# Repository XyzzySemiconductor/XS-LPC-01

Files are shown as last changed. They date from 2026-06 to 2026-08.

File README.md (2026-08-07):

   

# Tiny Tapeout Project: Liquid Pump Controller

A digital control chip to daily pump a tank empty. Approached as system design  for a whole product, of which the chip is the core but not only design work required.

- [chip datasheet](docs/LPC_Datasheet.pdf)
- [documentation for Tiny Tapeout chip](docs/info.md)
- [documentation for Tiny Tapeout tests](test/README.md)
- [documentation for MAX10 development fpga](max10/fpga.md)
- [documentation for forge production fpga](forge/forge.md)
- [documentation for the Dev board PCB](pcb/pcb.md)

Branches:
- main - TT design forefront, and Max 10M25 fpga accel of full system sims with hdmi display.
- lpc_emu - Max 10M04 fpga HW emulating the full TT chip (hdmi monitoring)
- lpc_test - Max 10M04 system emulator, chip testing or emulator testing.
- lpc_mon - Max 10M04 chip monitor, passive observation (hdmi)
  
## What is Tiny Tapeout?

Tiny Tapeout is an educational project that aims to make it easier and cheaper than ever to get your digital and analog designs manufactured on a real chip.

To learn more and get started, visit https://tinytapeout.com.

## Set up your Verilog project

1. Add your Verilog files to the `src` folder.
2. Edit the [info.yaml](info.yaml) and update information about your project, paying special attention to the `source_files` and `top_module` properties. If you are upgrading an existing Tiny Tapeout project, check out our [online info.yaml migration tool](https://tinytapeout.github.io/tt-yaml-upgrade-tool/).
3. Edit [docs/info.md](docs/info.md) and add a description of your project.
4. Adapt the testbench to your design. See [test/README.md](test/README.md) for more information.

The GitHub action will automatically build the ASIC files using [LibreLane](https://www.zerotoasiccourse.com/terminology/librelane/).

## Enable GitHub actions to build the results page

- [Enabling GitHub Pages](https://tinytapeout.com/faq/#my-github-action-is-failing-on-the-pages-part)

## Resources

- [FAQ](https://tinytapeout.com/faq/)
- [Digital design lessons](https://tinytapeout.com/digital_design/)
- [Learn how semiconductors work](https://tinytapeout.com/siliwiz/)
- [Join the community](https://tinytapeout.com/discord)
- [Build your design locally](https://www.tinytapeout.com/guides/local-hardening/)

## What next?

- [Submit your design to the next shuttle](https://app.tinytapeout.com/).
- Edit [this README](README.md) and explain your design, how it works, and how to test it.
- Share your project on your social network of choice:
  - LinkedIn [#tinytapeout](https://www.linkedin.com/search/results/content/?keywords=%23tinytapeout) [@TinyTapeout](https://www.linkedin.com/company/100708654/)
  - Mastodon [#tinytapeout](https://chaos.social/tags/tinytapeout) [@matthewvenn](https://chaos.social/@matthewvenn)
  - X (formerly Twitter) [#tinytapeout](https://twitter.com/hashtag/tinytapeout) [@tinytapeout](https://twitter.com/tinytapeout)
  - Bluesky [@tinytapeout.com](https://bsky.app/profile/tinytapeout.com)

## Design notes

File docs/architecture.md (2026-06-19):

### architecture

for now here's a quick block diagram

    +------------------+      +------------------+      +------------------+
    | Pump Current In  | ---> |  LPC Controller  | ---> | PWM Drive Output |
    +------------------+      |  - Thresholds    |      +------------------+
                              |  - Shutdown FSM  |
    +------------------+      |  - Debounce      |      +------------------+
    | AC Zero Detect   | ---> |  - Timing Logic  | ---> | Status / Debug   |
    +------------------+      +------------------+      +------------------+

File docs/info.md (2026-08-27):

<!---

This file is used to generate your project datasheet. Please fill in the information below and delete any unused
sections.

You can also include images in this folder and reference them in the markdown. Each image must be less than
512 kb in size, and the combined size of all images must be less than 1 MB.
-->

## How it works

A pump-out chip runs a pump until the tank is empty. A liquid pump controller, or LPC. The chips function is upon power up, and every 24hrs, turn on the pump, and using a current transformer (CT) measures the 60 Hz RMS current and observe a current drop indicating the tank has been emptied, or until a timeout has occurred and then turn off the pump. Leds indicate status, and button allows starting a pump out operation at any time.

A chip starts with a [Datasheet](LPC_Datasheet.pdf) where features are fleshed out, and boiled down to a few key diagrams: the chip block diagram, the system diagram, and a development platform to be used to bring up the chip as part of a product development. These are all before doing any design.

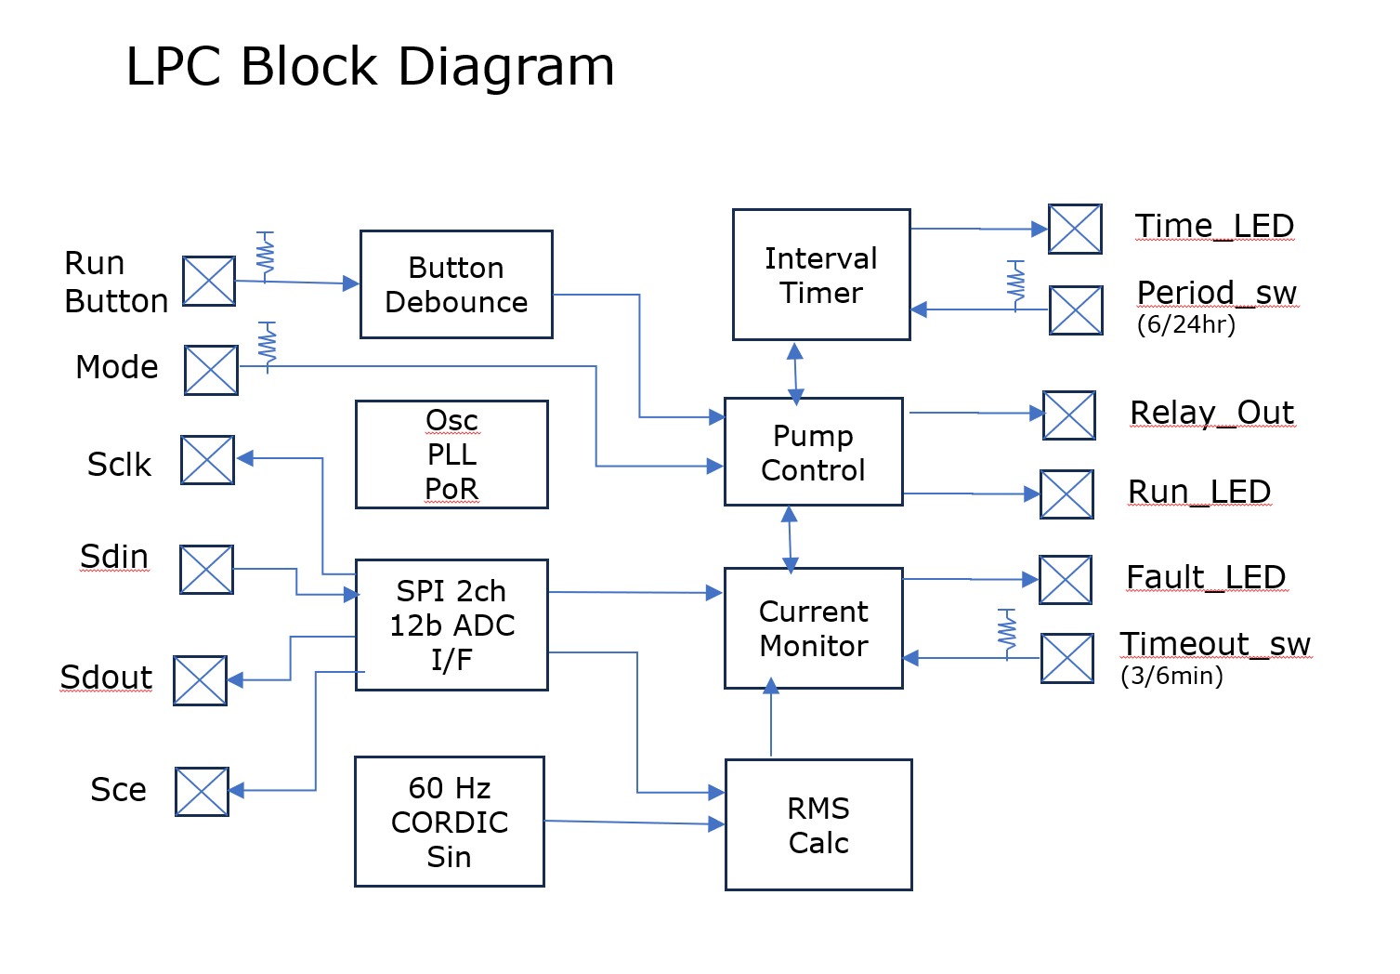
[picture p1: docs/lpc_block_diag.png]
Block Diagram


The chip  block diagram showing the key modules and critically the I/O and how it relates to the functions. A crisp clear picture of the chip's architecture.

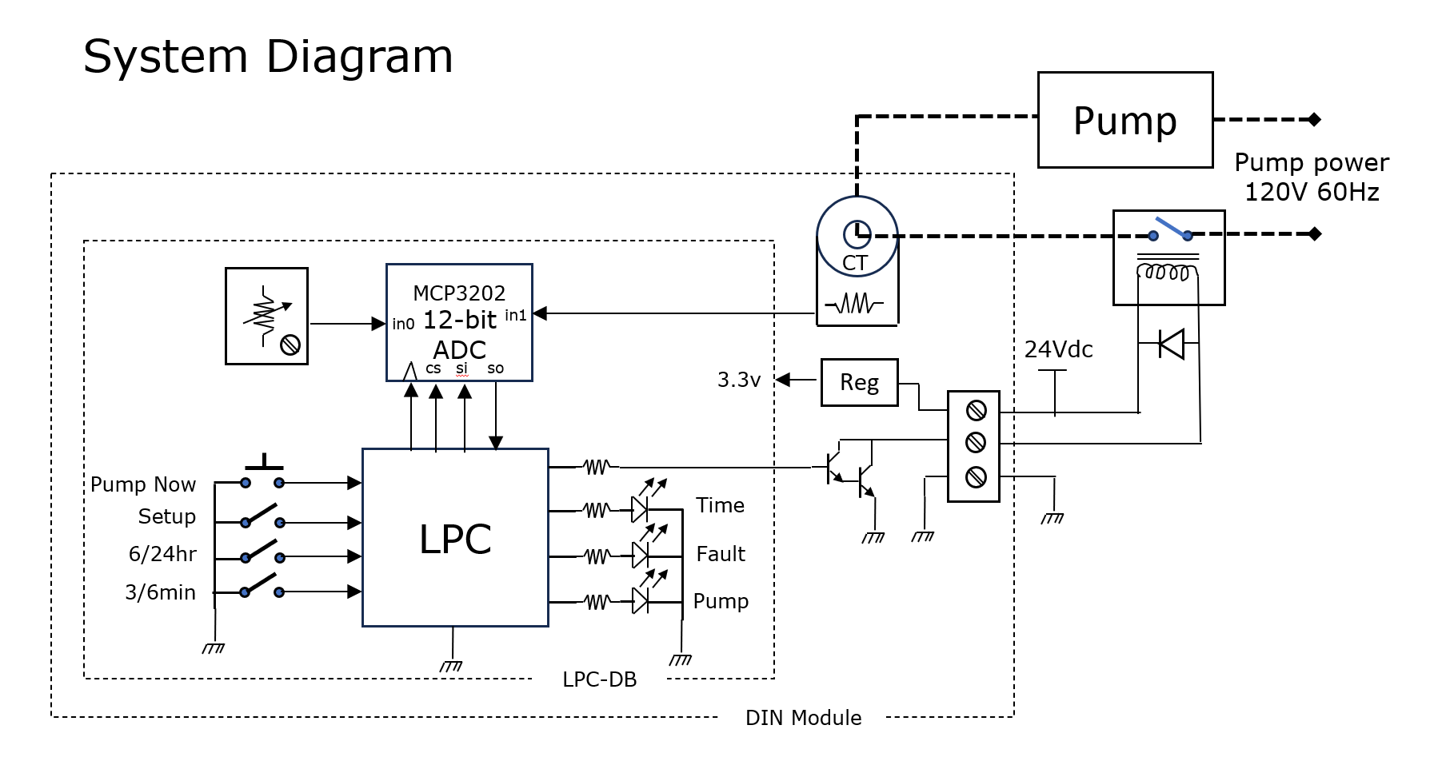
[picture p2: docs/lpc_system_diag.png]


The system diagram provides the context of the chip. How do the I/O connect to the rest of the system, what part of the system function is inside the chip and what part is outside. Another crisp clear picture of the chip from the outside.

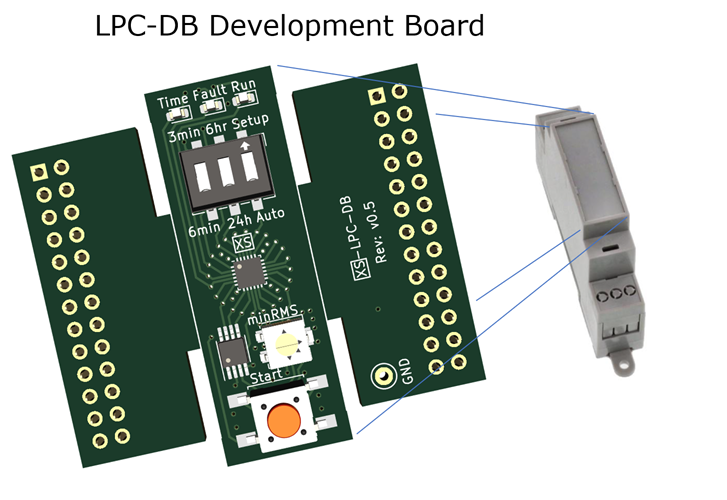
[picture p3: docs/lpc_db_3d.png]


In order to bring up a new chip requires a way to bring it to life. A development board is one way. Such a board provides a means to connect the chip into the system, and enable bring up and validation of the device an enable rapid product development by enabling full observability and emulation. 

For the LPC chip development board heart a 24 pin 3mm forge fpga with cut-away emulator wings. From the top we have the time, fault, run leds, the control dip switch, the LPC chip, a 2ch adc, potentiometer, and button.

## How to test

How did I test the design, and how should the chip be tested when it returns.

Design testing:

RTL testing at 16x speedup (changed internal dividers), with the testbench including ADC model, and a plant model. Used verilator to greatly speed up itterations, but still ran the TT icarus precision flow.

GL testing is much shorter, but one thing it does validate is to make sure the 16x speedup is not included in the gates (always fear parameters).

FPGA Max10 testing. Even with verilator full system simulation was not possible given the 24hour duty cycle, 15x true real time was used with the ADC and plant models being synthesized into the fpga along with the LPC_core.sv

Chip Testing

A FPGA Max 10 chip tester was designed by putting the adc model and plant model into an fpga. To test this a 2nd Max 10 was setup as a chip emulator, and to observe the interaction between the 2 a 3rd Max 10 was setup as a monitor with 32MByte of storage PSRAM and HDMI vga, fully observed teh chips's I/O. All of these boards inteconnected via the LPC dev board emulation header. Teh TT chip will plug into this emulation header with the Tester and Monitor FPGAs.

A development board was fully designed and implemented with the chip I/O all wired to emulation headers. The TT develoement board pmods will be jump wired to the emulation header pins. The Max10 monitor fpga board will be able to observe the interaction between the TT chip and the LPC dev board. The LPC dev board connects to a power board contain the CT (current transformer) and pump relay. The bring up of the dev board used the chip Max 10 emulator and the Max 10 monitor.

Renesas forge 1k-lut OTP fpga emulation of the TT chip. I find these chips are about the equivalent of a 1x2 TT design with similar (less) I/O. They are self contained with build in Osc, PLL, and power on reset, and configure from OTP in 10ms. The LPC design was ported and implemented in a Forge fpga. The FPGA itself was tested against the Max10 tester, and then connected to the dev board by the emulation header, and penultimately soldered onto the dev board, and run in-system.

## External hardware

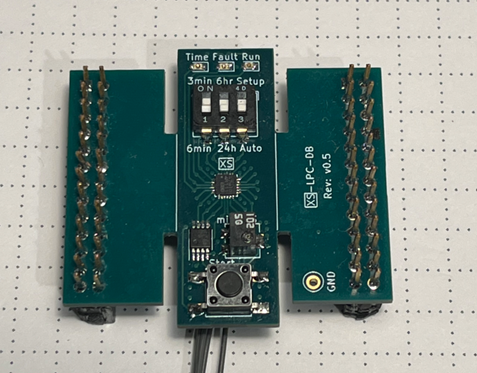
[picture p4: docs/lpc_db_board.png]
Development Board


The LPC dev board with the 3mm x 3mm forge fpga mounted. This board has been tested in system. The TT dev baord can be jumpered to the header (and the forge held in reset) to allow full system testing.

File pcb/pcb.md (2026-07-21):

### LPC Development board.

The LPC-DB PCB is a development board used to bring up and validate the LPC pump-controller ASIC by providing a controlled, 
low-voltage environment for CT sensing, signal conditioning, adc and digital interfacing during early hardware testing. 
It contains the CT burden input stage, protection components, calibration path, regulated supplies, and 
emulation header instrumenting the LPC chip IO. With the emulators wings clipped, 
the fits in the face of a Din rail module for field testing.

It does not switch mains and relies on external hardware for pump actuation.

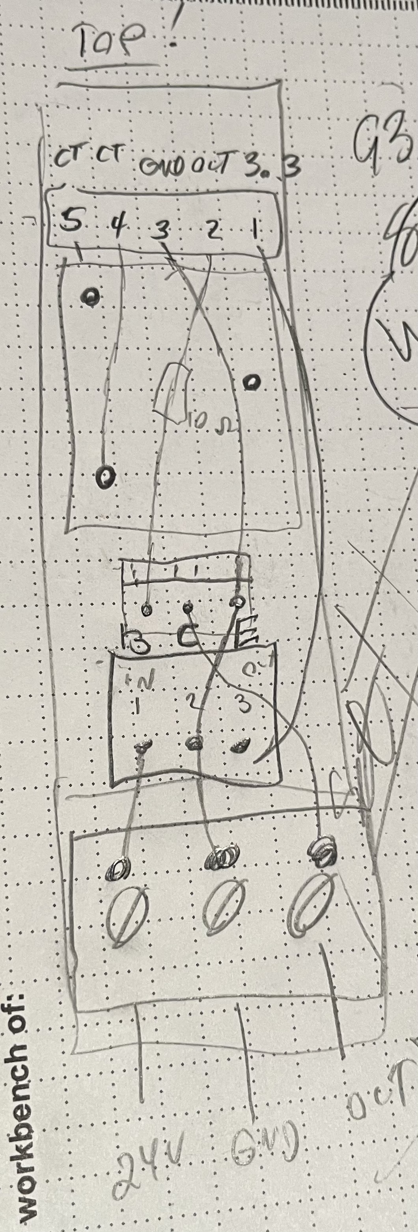
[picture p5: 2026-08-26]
docs/din_lower_schematic.jpeg

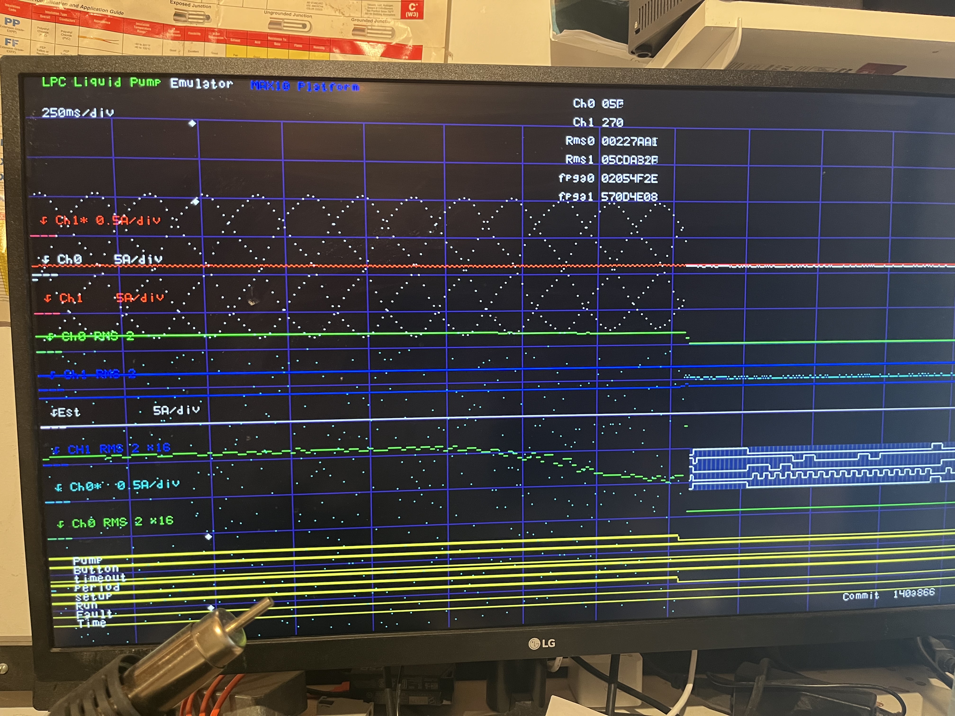
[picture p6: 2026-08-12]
docs/140a866_field_run_pump_empty_02.jpeg

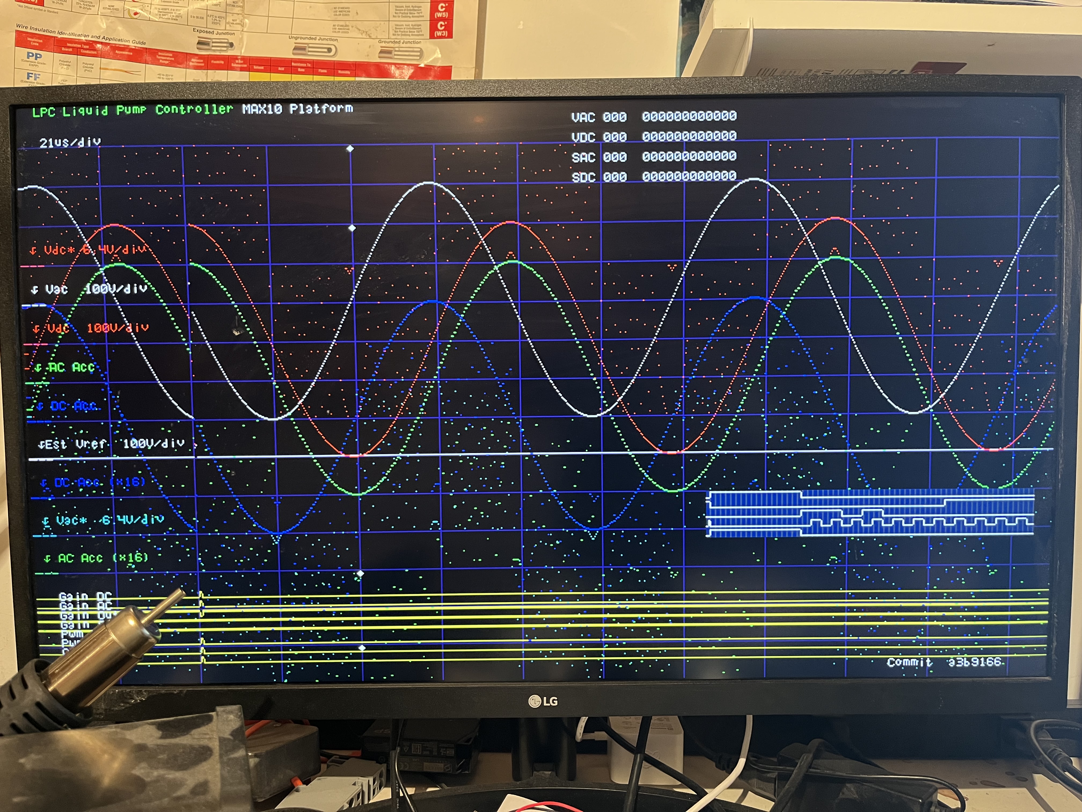
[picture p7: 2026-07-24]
docs/a3b9166.jpeg

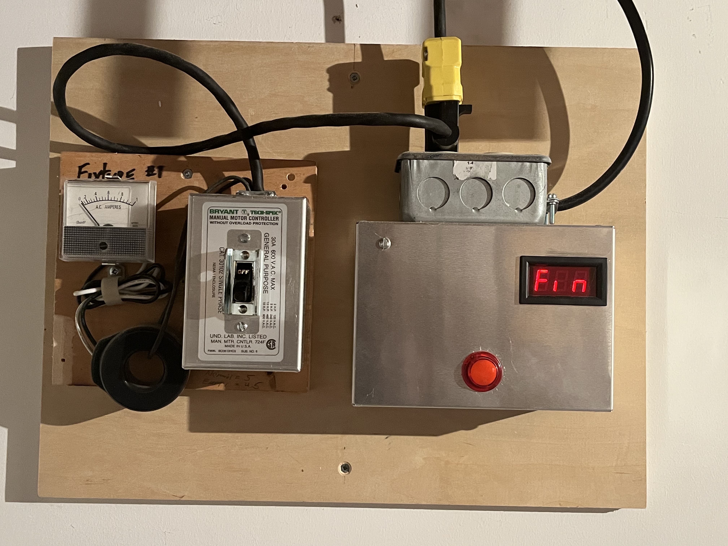
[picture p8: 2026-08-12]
docs/140a866_field_run_pump_empty_05.jpeg

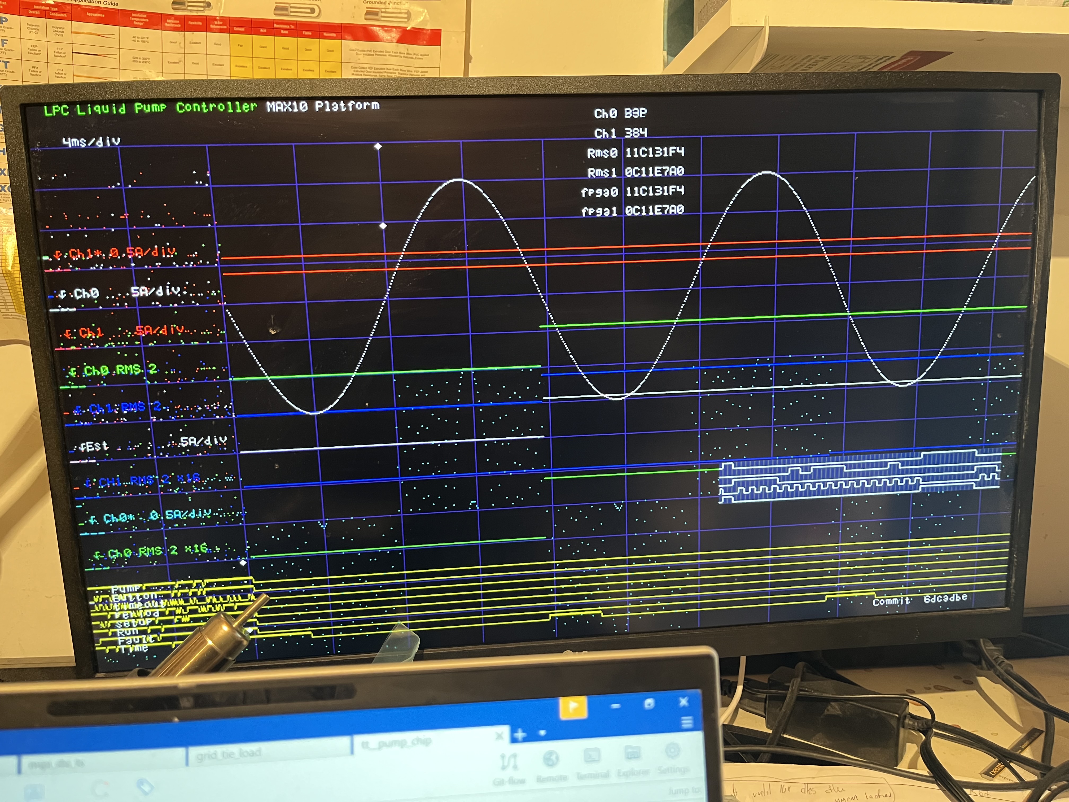
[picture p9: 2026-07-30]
docs/6dcadbe.jpeg

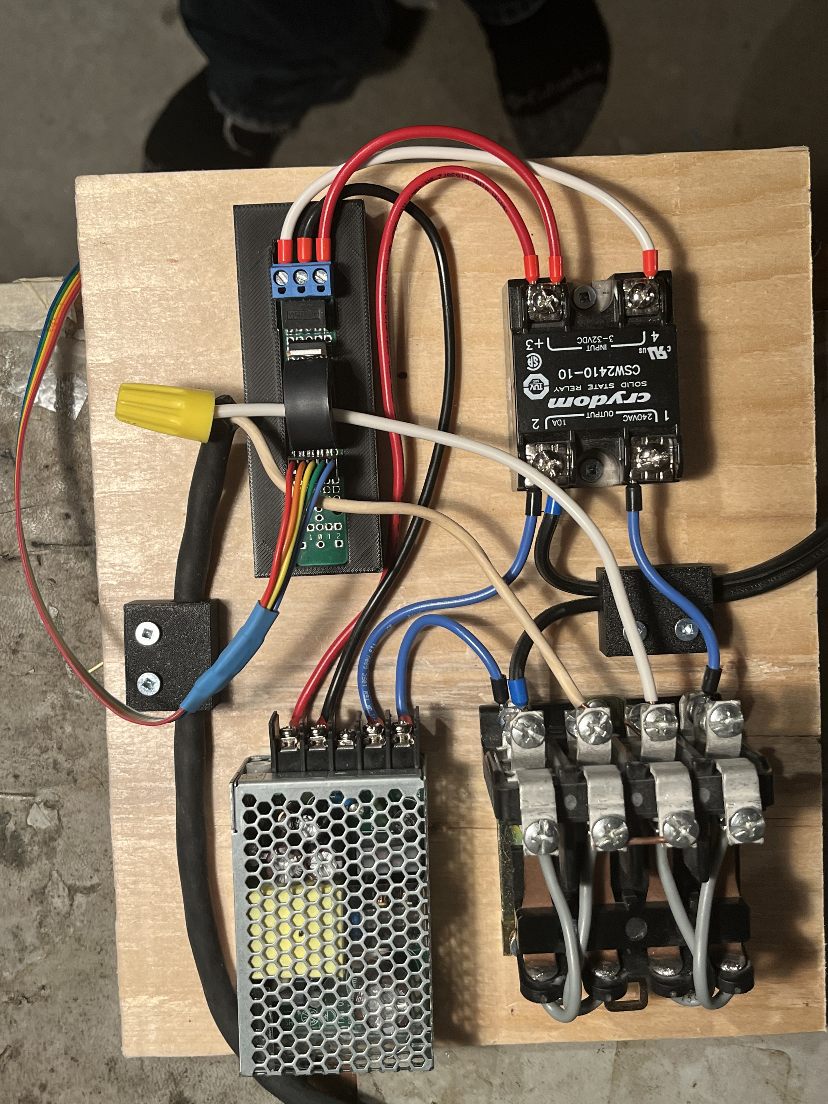
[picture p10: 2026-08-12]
docs/140a866_field_run_pump_empty_04.jpeg

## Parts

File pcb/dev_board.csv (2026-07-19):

Reference | Value | Footprint | Datasheet | DPN | Qty
C1, C2, C4, C9, C10 | 1u | Capacitor_SMD:C_0603_1608Metric | ~ | 399-C0603C105K3RAC7867CT-ND | 5
C3, C5, C6 | 22n | Capacitor_SMD:C_0603_1608Metric | ~ | 445-5663-1-ND | 3
C8 | 4.7u | Capacitor_SMD:C_1206_3216Metric | ~ | 399-C1206C475K5PAC7800CT-ND | 1
C11 | 0.1u | Capacitor_SMD:C_0603_1608Metric | ~ | 399-C0603C104K3RAC7867CT-ND | 1
C12 | 10u | Capacitor_SMD:C_1206_3216Metric | ~ | 399-C1206C106K4PAC7800CT-ND | 1
D1 | RUN | LED_SMD:LED_0603_1608Metric | https://www.digikey.ca/en/products/detail/kingbright/APTD1608LSYCK/7043071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 | 754-2039-1-ND | 1
D2 | FLT | LED_SMD:LED_0603_1608Metric | https://www.digikey.ca/en/products/detail/kingbright/APTD1608LSYCK/7043071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 | 754-2039-1-ND | 1
D3 | TME | LED_SMD:LED_0603_1608Metric | https://www.digikey.ca/en/products/detail/kingbright/APTD1608LSYCK/7043071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 | 754-2039-1-ND | 1
D6 | DT1042-04SO-7 | Package_TO_SOT_SMD:SOT-23-6 | https://www.digikey.ca/en/products/detail/diodes-incorporated/DT1042-04SO-7/4457877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 | DT1042-04SO-7DICT-ND | 1
J1, J2 | Conn_02x13_Odd_Even | Connector_PinSocket_2.54mm:PinSocket_2x13_P2.54mm_Vertical | https://www.digikey.ca/en/products/detail/samtec-inc/ESW-113-12-T-D/7207386 | ESW-113-12-T-D-ND | 2
J4 | Conn_01x05 | Connector_JST:CONN_B5B-ZR-SM4-TF_JST | https://www.digikey.ca/en/products/detail/jst-sales-america-inc/B5B-ZR-SM4-TF/926591 | 455-1684-1-ND | 1
R1 | 0R | Resistor_SMD:R_0603_1608Metric |  | P0.0GCT-ND | 1
R2-R4, R6, R7 | 1K | Resistor_SMD:R_0603_1608Metric |  | 541-1.00KHCT-ND | 5
R5 | DNI | Resistor_SMD:R_0603_1608Metric |  | ~ | 1
R8, R11-R14, R16 | 47 | Resistor_SMD:R_0603_1608Metric |  | 541-47.0HCT-ND | 6
R9 | 3k3 | Resistor_SMD:R_0603_1608Metric |  | 311-3.30KHRCT-ND | 1
R10 | 1K | Potentiometer_SMD:Potentiometer_Bourns_3224J_Horizontal | https://www.digikey.ca/en/products/detail/nidec-components/SM-42TW102/1632327 | SM-42TW102CT-ND | 1
SW1 | SW_DIP_x03 | Button_Switch_SMD:SW_DIP_SPSTx03_Slide_6.7x9.18mm_W6.73mm_P2.54mm_LowProfile_JPin |  | 563-CFS-0300TACT-ND | 1
SW2 | Start | myspace pcb:SW_SPST_HP03 | https://www.digikey.ca/en/products/detail/nkk-switches/HP0315AFKP2-R/1242035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 | 360-2595-1-ND | 1
U1 | XS-LPC-01 | myspace pcb:QFN-24-3x3mm | https://github.com/ericpearson1313/tt_pump_out_chip | ~ | 1
U2 | MCP3202 | Package_SO:MSOP-8_3x3mm_P0.65mm | https://ww1.microchip.com/downloads/aemDocuments/documents/APID/ProductDocuments/DataSheets/21034F.pdf | MCP3202-CI/MS-ND | 1
U3 | NCP114ASN280T1G | Package_TO_SOT_SMD:SOT-23-5 | https://www.digikey.ca/en/products/detail/onsemi/NCP114ASN280T1G/6560603 | NCP114ASN280T1GOSCT-ND | 1
U6 | TLV74311 | Package_TO_SOT_SMD:SOT-23-5 | https://www.digikey.ca/en/products/detail/texas-instruments/TLV74311PDBVR/7593919 | 296-50002-1-ND | 1

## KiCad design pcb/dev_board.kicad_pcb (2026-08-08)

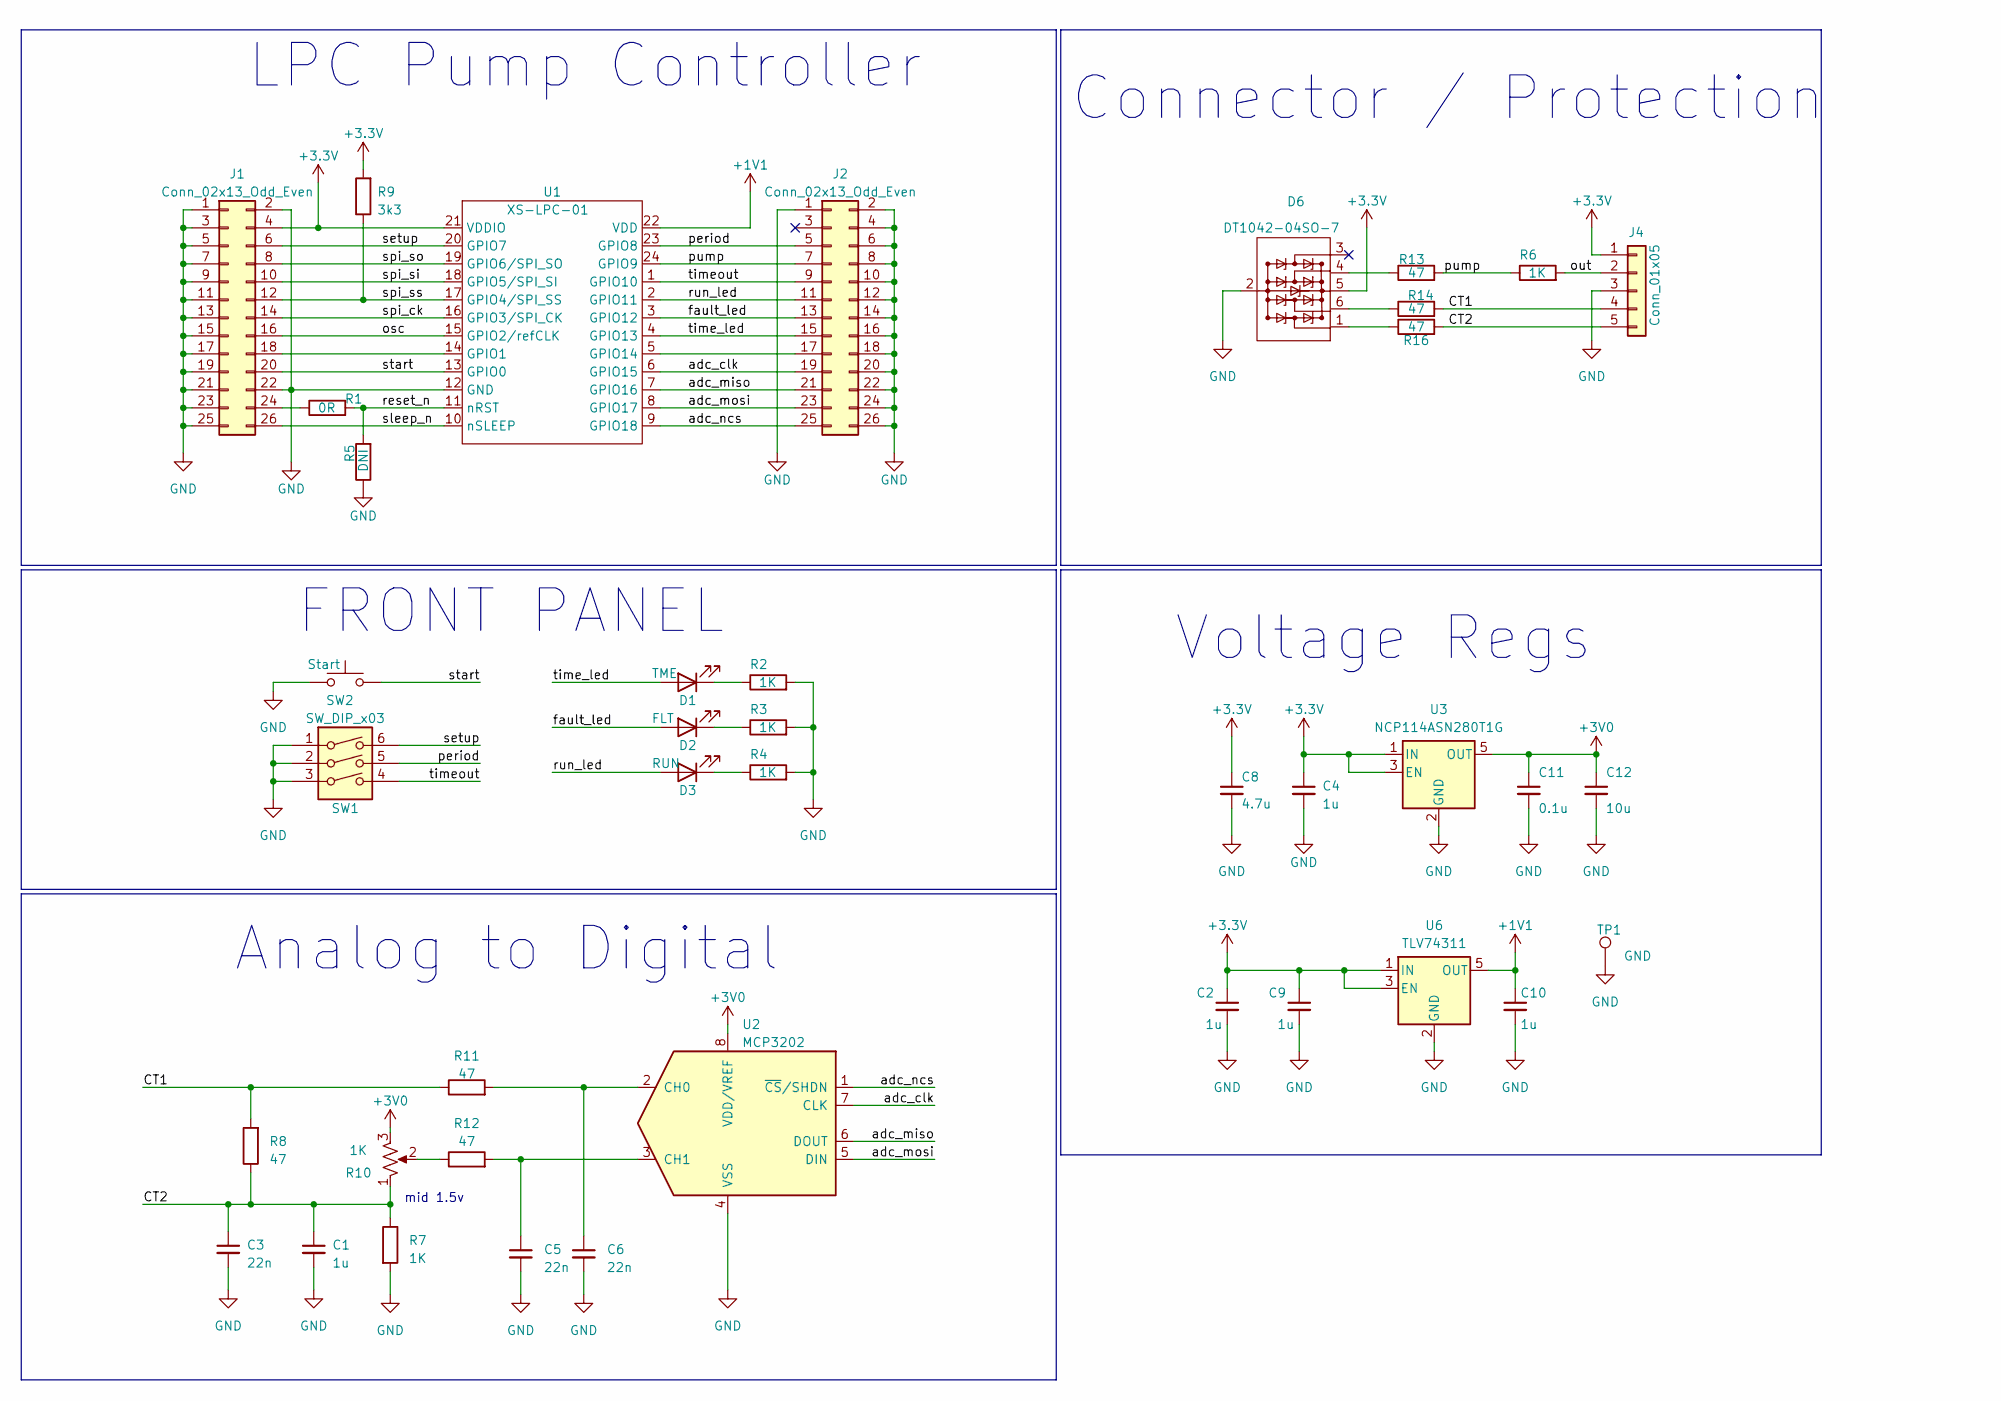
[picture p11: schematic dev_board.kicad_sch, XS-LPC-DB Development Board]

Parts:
C1, C2, C4, C9, C10: 1u; C_0603_1608Metric
C3, C5, C6: 22n; C_0603_1608Metric
C8: 4.7u; C_1206_3216Metric
C11: 0.1u; C_0603_1608Metric
C12: 10u; C_1206_3216Metric
D1: TME; LED_0603_1608Metric
D2: FLT; LED_0603_1608Metric
D3: RUN; LED_0603_1608Metric
D6: DT1042-04SO-7; SOT-23-6
J1, J2: Conn_02x13_Odd_Even; PinSocket_2x13_P2.54mm_Vertical
J4: Conn_01x05; CONN_B5B-ZR-SM4-TF_JST
R1: 0R; R_0603_1608Metric; JLC C491211
R2, R3, R4, R6, R7: 1K; R_0603_1608Metric; JLC C319967
R5: DNI; R_0603_1608Metric; JLC C491211
R8, R11, R12, R13, R14, R16: 47; R_0603_1608Metric; JLC C319967
R9: 3k3; R_0603_1608Metric; JLC C319967
R10: 1K; Potentiometer_Bourns_3224J_Horizontal
SW1: SW_DIP_x03; SW_DIP_SPSTx03_Slide_6.7x9.18mm_W6.73mm_P2.54mm_LowProfile_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
SW2: Start; SW_SPST_HP03
TP1: GND; TestPoint_Keystone_5000-5004_Miniature
U1: XS-LPC-01; QFN-24-3x3mm
U2: MCP3202; MSOP-8_3x3mm_P0.65mm
U3: NCP114ASN280T1G; SOT-23-5
U6: TLV74311; SOT-23-5

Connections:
+1V1: C10.1, U1.22 (VDD), U6.5 (OUT)
+3.3V: C2.1, C4.1, C8.1, C9.1, D6.5 (vdd), J1.4, J4.1, R9.2, U1.21 (VDDIO), U3.1 (IN), U3.3 (EN), U6.1 (IN), U6.3 (EN)
+3V0: C11.1, C12.1, R10.3, U2.8 (VDD/VREF), U3.5 (OUT)
/CT1: J4.4, R8.2, R11.1, R14.2
/CT2: C1.1, C3.1, J4.5, R7.1, R8.1, R10.1, R16.2
/adc_clk: J2.19, U1.6 (GPIO15), U2.7 (CLK)
/adc_miso: J2.21, U1.7 (GPIO16), U2.6 (DOUT)
/adc_mosi: J2.23, U1.8 (GPIO17), U2.5 (DIN)
/adc_ncs: J2.25, U1.9 (GPIO18), U2.1 (~CS/SHDN)
/fault_led: D2.2 (A), J2.13, U1.3 (GPIO12)
/osc: J1.16, U1.15 (GPIO2/refCLK)
/out: J4.2, R6.2
/period: J2.5, SW1.5, U1.23 (GPIO8)
/pump: J2.7, R6.1, R13.2, U1.24 (GPIO9)
/reset_n: R1.2, R5.2, U1.11 (nRST)
/run_led: D3.2 (A), J2.11, U1.2 (GPIO11)
/setup: J1.6, SW1.6, U1.20 (GPIO7)
/sleep_n: J1.26, U1.10 (nSLEEP)
/spi_ck: J1.14, U1.16 (GPIO3/SPI_CK)
/spi_si: J1.10, U1.18 (GPIO5/SPI_SI)
/spi_so: J1.8, U1.19 (GPIO6/SPI_SO)
/spi_ss: J1.12, R9.1, U1.17 (GPIO4/SPI_SS)
/start: J1.20, SW2.2, U1.13 (GPIO0)
/time_led: D1.2 (A), J2.15, U1.4 (GPIO13)
/timeout: J2.9, SW1.4, U1.1 (GPIO10)
GND: C1.2, C2.2, C3.2, C4.2, C5.2, C6.2, C8.2, C9.2, C10.2, C11.2, C12.2, D6.2 (vss), J1.1, J1.2, J1.3, J1.5, J1.7, J1.9, J1.11, J1.13, J1.15, J1.17, J1.19, J1.21, J1.22, J1.23, J1.25, J2.1, J2.2, J2.4, J2.6, J2.8, J2.10, J2.12, J2.14, J2.16, J2.18, J2.20, J2.22, J2.24, J2.26, J4.3, R2.2, R3.2, R4.2, R5.1, R7.2, SW1.1, SW1.2, SW1.3, SW2.1, TP1.1, U1.12 (GND), U2.4 (VSS), U3.2 (GND), U6.2 (GND)
unnamed: D1.1 (K), R2.1
unnamed: D2.1 (K), R3.1
unnamed: D3.1 (K), R4.1
unnamed: D6.4 (K1), R13.1
unnamed: D6.6 (K2), R14.1
unnamed: D6.1 (X1), R16.1
unnamed: J1.18, U1.14 (GPIO1)
unnamed: J1.24, R1.1
unnamed: J2.17, U1.5 (GPIO14)
unnamed: R10.2, R12.1
unnamed: C6.1, R11.2, U2.2 (CH0)
unnamed: C5.1, R12.2, U2.3 (CH1)

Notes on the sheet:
LPC Pump Controller
Voltage Regs
FRONT PANEL
Connector / Protection
Analog to Digital
mid 1.5v

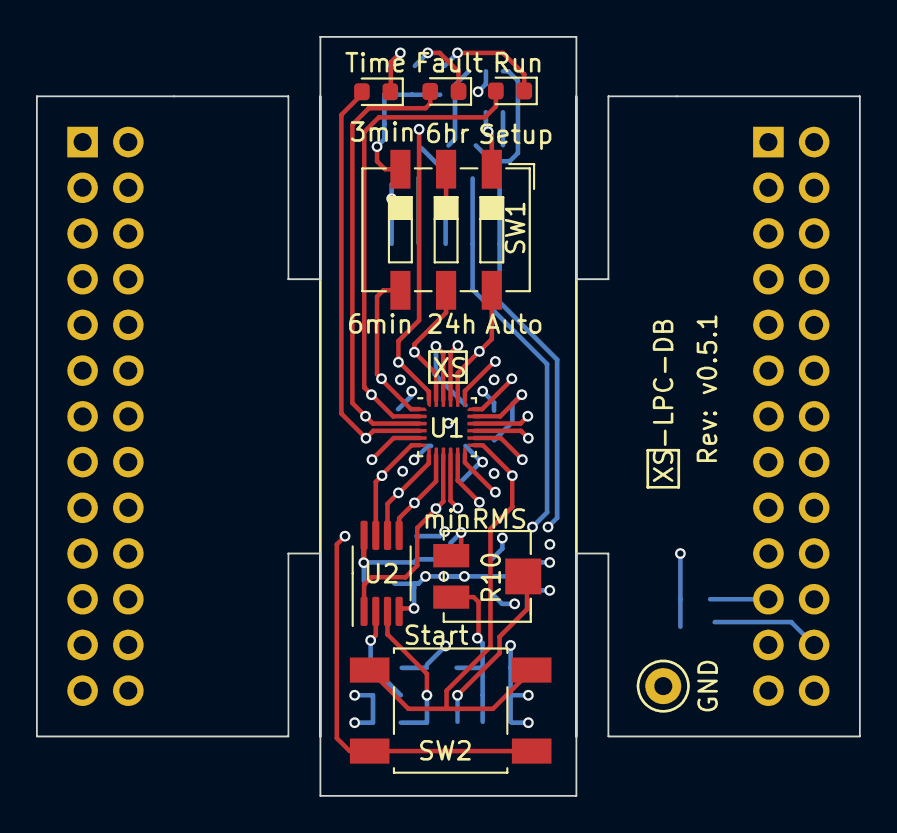
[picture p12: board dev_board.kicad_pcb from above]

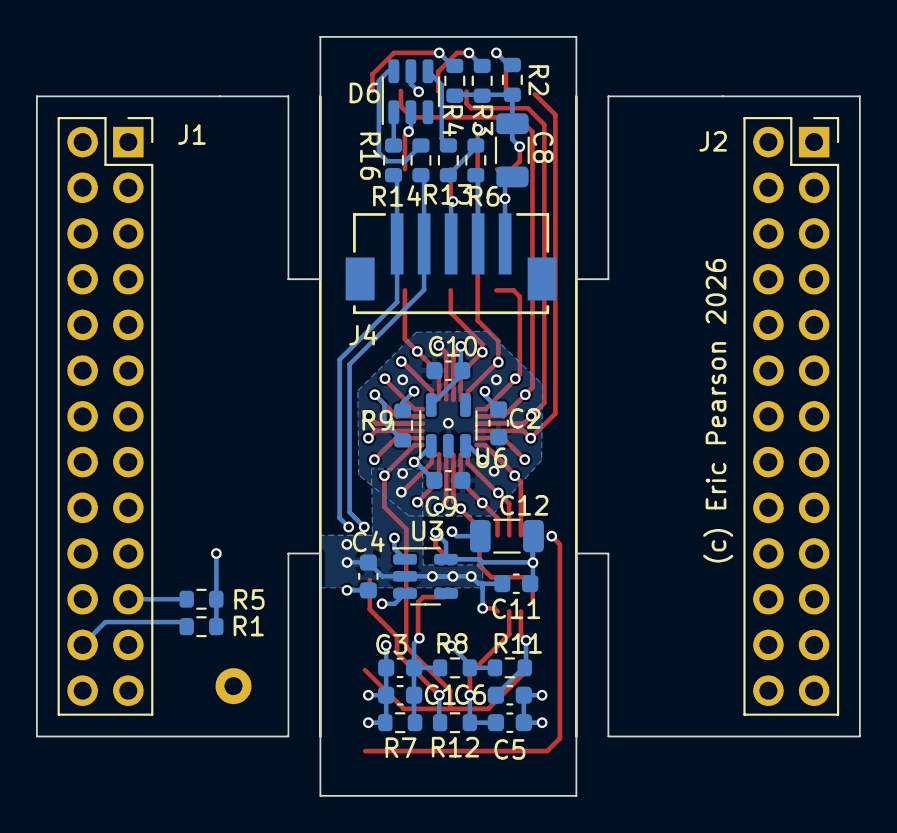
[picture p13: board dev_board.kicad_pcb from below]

Board: 6 copper layers, 45.7 x 42.2 mm, 40 parts (31 on the bottom side), 38 nets.

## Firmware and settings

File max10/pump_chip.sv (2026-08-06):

// vim: ts=4:
`timescale 1ns / 1ps
module pump_chip

#(
	// Parameter Declarations
	parameter UNIQ_ID = 32'h0000_0000
)

(
	/////////////
	// LPC CHIP IO
	/////////////

	// Input Buttons
	//input  logic button, // pin 140

	// Output LED/SPK
	//output logic time_led, // pin 101
	//output logic fault_led, // pin 99
	//output logic run_led, // pin 100
	//output logic pump_out, // pin 124

	// External Current Control Input
	//input	 logic setup_sw,  // pin 62 
	//input  logic period_sw,  // pin 135
	//input  logic timeout_sw, // pin 66 

	// ADC I/O (spi)
	//output logic adc_ncs,  // pin 132
	//output logic adc_clk,  // pin 105
	//input  logic adc_miso, // pin 106
	//output logic adc_mosi, // pin 65 

	////////////
	// DEBUG IO
	////////////
	
	// Bank 1A: emualtor LEDs
	output [8:1] anain,
	
	// Bank 7, keypad input
	inout [6:0] digio,

	
	// SPI8 Bus, to PSRAM
	inout  wire [7:0]  spi8_data_pad,   //   pad_io.export
	inout  wire spi_clk0,
	inout  wire spi_ncs,
	inout  wire spi_ds,
	inout  wire spi_nrst,
	
	// HDMI Output (Tru LVDS)
	output logic		hdmi2_d0,
	output logic		hdmi2_d1,
	output logic		hdmi2_d2,
	output logic      hdmi2_ck,
	
	// Input clock, reset
	output logic clk_out, // Differential output
	input logic clk_in,	 // Reference 48Mhz or other
	input logic reset_n
);

	// all I/O is internally emulated in the code as we are a full simulation
	logic adc_ncs;   	// pin 132
	logic adc_clk;   	// pin 105
	logic adc_miso;  	// pin 106
	logic adc_mosi;  	// pin 65 
	logic setup_sw;  	// pin 62 
	logic period_sw; 	// pin 135
	logic timeout_sw;	// pin 66 
	logic button; 		// pin 140
	logic time_led; 	// pin 101
	logic fault_led; 	// pin 99
	logic run_led; 	// pin 100
	logic pump_out; 	// pin 124



	logic [4:0] key; // keypad, bit 4 indicates pressed

	// PLL (only 1 PLL in E144 package!)

	logic clk;	// global 48Mhz clock
	logic clk4; // global 192MhZ spi8 clk
	logic hdmi_clk; 	// Pixel clk, apparentlyi can support 720p
	logic hdmi_clk5;  // 5x pixel clk clock for data xmit, 10b*3=30/3lanes=10ddr=5 

	trial_pll _spll(
		.inclk0 (clk_in),		// External clock input
		.c0     (clk_out), 	// Flash Clock 6Mhz, also External clock output differential
		.c1	  (clk),			// Global Clock ADC rate 48 Mhz
		.c2	  (clk4),		// Global Clock SPI8 rate 192 Mhz
		.c3	  (hdmi_clk),	// HDMI pixel clk
		.c4	  (hdmi_clk5)  // HDMI ddr clock 5x
		);
		
	// delayed from fpga config and external reset d-assert

	logic [3:0] reset_shift = 0; // initial value upon config
	always @(posedge clk) begin
			if( !reset_n ) begin
				reset_shift <= 4'h0;
			end else begin
				if( reset_shift != 4'HF ) begin
					reset_shift[3:0] <= reset_shift[3:0] + 4'h1;
				end else begin
					reset_shift[3:0] <= reset_shift[3:0];
				end
			end
	end

	logic reset;
	assign reset = (reset_shift[3:0] != 4'hF) ? 1'b1 : 1'b0; // reset de-asserted after all bit shifted in 


	// AIN LED Display with counter
	assign anain[4:1] = ~{ time_led, fault_led, run_led, pump_out }; // active low leds

	logic [24:0] count;
	always @(posedge clk) begin
		count <= count + 1;
	end
	assign anain[8:5] = 3'b111; //count[24:21];


	/////////////////////////////////
	/////////////////////////////////
	////
	////  Pump Chip (DUT) 
	////
	/////////////////////////////////
	/////////////////////////////////

  // Fpga probes

	logic [31:0] fpga_probe;	
	logic [31:0] fpga_probe2;	
	logic [11:0] fpga_probe3;	
	

	// Register ADC I/O
		
	wire ncs_io, clk_io, mosi_io, miso_io; 
	always @(posedge clk) adc_ncs <= ncs_io;
	always @(posedge clk) adc_clk <= clk_io;
	always @(posedge clk) adc_mosi <= mosi_io;
	always @(posedge clk) miso_io <= adc_miso; 
	
	// PUMP Chip CORE emulation/test
	localparam NUM_SAMPLE = 3750;//250; // // 3750 is realtime, 250 is 15x realtime
	lpc_core #(
		.NUM_SAMPLE( NUM_SAMPLE ), 
		.MAX_RMS( 1103 ) // 15 amps
	) i_core (
		// System
		.clk			( clk ),
		.reset 		( reset ),
		.fpga_probe ( fpga_probe ),
		.fpga_probe2 ( fpga_probe2 ),
		// Dig IO
		.button		( button ),
		.setup_sw	( setup_sw ),
		.period_sw	( period_sw ),
		.timeout_sw	( timeout_sw ),
		.time_led	( time_led ),
		.fault_led	( fault_led ),
		.run_led		( run_led ),
		.pump_out	( pump_out ),
		// ADC Interface
		.adc_ncs    ( ncs_io ),
		.adc_clk		( clk_io ),
		.adc_mosi	( mosi_io ),
		.adc_miso	( miso_io )
	);

  	//////////////////////
  	//////////////////////
	//
  	// ADC System Simulation
	//
  	/////////////////////
  	//////////////////////

	logic [11:0] ref_in;
	/////////////
	// Sim Time
	/////////////
	
	// 4 Hz (or 60 Hz for 15x faster that realtime
	logic [23:0] tick_cnt;
	logic sys_tick;
	logic [19:0] time_cnt; // sim time count is count of tick's 

	always_ff @(posedge clk) 
		if( NUM_SAMPLE == 250 ) begin
			tick_cnt <= ( reset ) ? 0 : ( tick_cnt == (48000000 / 60) - 1 ) ? 0 : tick_cnt + 1;
			sys_tick <=  ( tick_cnt == (48000000 / 60) - 1 ) ? 1'b1 : 1'b0 ;	// 15x faster realtime
			time_cnt <= ( reset ) ? 0 : ( tick_cnt == (48000000 / 60) - 1 ) ? time_cnt + 1 : time_cnt;
		end else begin
			tick_cnt <= ( reset ) ? 0 : ( tick_cnt == (48000000 / 4) - 1 ) ? 0 : tick_cnt + 1;
		   sys_tick <=  ( tick_cnt == (48000000 / 4 ) - 1 ) ? 1'b1 : 1'b0 ; 	// Realtime	
			time_cnt <= ( reset ) ? 0 : ( tick_cnt == (48000000 / 4) - 1 ) ? time_cnt + 1 : time_cnt;
		end
	
	// Model Inputs
	logic empty, stall, n_empty;
	
	// Test Inputs driving.
	always_comb begin
		// Defaut Nominal, Test 1
		// ADC Inptu
		ref_in = 663; // 663 ~9A RMS
		// Chip Inputs
		button = 1;
		setup_sw = 1;
		period_sw  = 1; 
		timeout_sw = 0;  /// default 3 min
		// Model Inputs
		empty = 0;
		stall = 0;
		n_empty = 0;
		
		// Test 2, short cycle fault 
		//empty = 1; // observed 3 blink fault code
		
		// Test 3, timeout faults 
		//n_empty = 1; // observed 1 blink fault code (3min, 6min, 12min, 24min each tested)
		
		// Test 4, stall over current fault test
		//stall = 1; // Observed 2 blink fault code
		
		// Test 5: button restart
		//button = ( 	time_cnt == 'h40 ) ? 1'b0 : 1'b1;
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

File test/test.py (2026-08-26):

# SPDX-FileCopyrightText: © 2024 Tiny Tapeout
# SPDX-License-Identifier: Apache-2.0

import cocotb
from cocotb.clock import Clock
from cocotb.triggers import ClockCycles


@cocotb.test()
async def test_project(dut):
    dut._log.info("Start")

    # Set the clock period to 48 MHz
    clock = Clock(dut.clk, 20832, unit="ps")
    cocotb.start_soon(clock.start())

    # Reset
    dut._log.info("Reset")
    dut.ena.value = 1
    dut.ui_in.value = 0
    dut.uio_in.value = 0
    dut.rst_n.value = 0
    await ClockCycles(dut.clk, 10)
    dut.rst_n.value = 1

    try:
        _ = dut.user_project.i_core.rms_hold_ct.value
        GL_MODE = False
        dut._log.info("RTL Sim")
    except AttributeError:
        GL_MODE = True
        dut._log.info("Gate Sim")

    dut._log.info("Test project behavior")

    # Set the input values you want to test
    # dut.ui_in.value = 20
    # dut.uio_in.value = 30

    # Wait for one clock cycle to see the output values
    assert dut.uio_out.value == (3750>>4)
    if not GL_MODE:
        assert int(dut.user_project.i_core.rms_hold_ct.value) == 0
        assert int(dut.user_project.i_core.rms_hold_ct.value) == 0
    dut._log.info("60 Hz cycle")
    if GL_MODE:
        await ClockCycles(dut.clk, 50000 * 16 + 3200 * 10 )
    if not GL_MODE:
        await ClockCycles(dut.clk, 50000 * 16 * 16)
    #check that flags are OK (and not X)
    assert dut.pump_out.value  == 1
    #assert dut.time_led.value  == 1
    assert dut.run_led.value   == 1
    # check RMS values
    if GL_MODE:
        assert dut.fault_led.value == 1
    if not GL_MODE:
        assert dut.fault_led.value == 0
        assert int(dut.user_project.i_core.rms_hold_ct.value) < (1200*1200*3750)
        assert int(dut.user_project.i_core.rms_hold_ct.value) > (1000*1000*3750)
        assert int(dut.user_project.i_core.rms_hold_ct.value) == 4154053977
        assert int(dut.user_project.i_core.rms_hold_ref.value) < (600*600*3750)
        assert int(dut.user_project.i_core.rms_hold_ref.value) > (500*500*3750)
        #assert int(dut.user_project.i_core.rms_hold_ref.value) == 1038448055

    # The following assersion is just an example of how to check the output values.
    # Change it to match the actual expected output of your module:
    #assert dut.uo_out.value == 50

    # Keep testing the module by changing the input values, waiting for
    # one or more clock cycles, and asserting the expected output values.

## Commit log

2026-07-12 Revise pump-out chip description in info.md
    Corrected spelling errors and improved clarity in the description of the pump-out chip functionality.
2026-07-14 LPC Architecture Draft datasheet (chip, system, dev board).
2026-07-14 48Mhz system clock --> 15 Khz sample clock, 250 samples per 60 Hz cycle, 600 Khz spi clk.
2026-07-17 V0.1 schematic complete, pcb placed. emulator connections, 24-stqfn LPC fanout in place.
    [dev_board.kicad_pcb, dev_board.kicad_sch]
2026-07-17 Update BOM to v0.1 with in-stock, current Digikey Parts Numbers
    [dev_board.csv, dev_board.kicad_sch]
2026-07-19 v0.3 emulator winged, clean routed PCB, schem, Digikey BOM. For review and cleanup.
    [dev_board.csv, dev_board.kicad_pcb, dev_board.kicad_sch]
2026-07-21 Enhance FPGA use section for MAX10 details
    Expanded the FPGA use section to include specific functionalities of the MAX10 FPGA, detailing its role in chip development, PCB bringup, and testing.
2026-07-21 Fixup paths and remove boilerplate assert
    [test.py]
2026-07-24 a3b9166 hdmi scope 4M sample @ 15khs, and window 256 bits @ 6mhz, text scales need fixing
2026-07-26 word serial datapath for 60Hz rms^2 = sum[y*sin]^2+sum[y*cos]^2
2026-07-26 rms control logic for ADC word serial multply-accumulate rough in
2026-07-29 hdmi zoom scale overlay, digitial trace legend, and remove yet unused scalar displays. 10M25 sim env running. Ready to add realtime system tests on the LPC_core.
2026-07-29 Bringup of LPC core in fpga sim in progress. Probes of internal and testbench singalls (and fixing up signed number representations). dynamic hex overlays show real signal values.
    [pump_chip.sv]
2026-07-30 Integrated pump model in TT tb.v, and centered zoom caret on display
2026-07-30 Pump model constants for 15A, 10A, 9A, and 0,1A setpoints.
2026-07-31 pump model pump basic cycle { startup, run, empty } operational.
2026-07-31 9396391 artefact pic of pump model running {start, run, and then empty} instrumented.
2026-07-31 LPC bringup test #1, Power on --> LPC perfectly nomial pump cycle. After some fixes to LPC Logic and test conditions.
    [pump_chip.sv]
2026-08-02 Add pump_interface_board.jpeg — physical 120V relay interface. Rainbow ribbon cable connects to DB for LPC bring‑up.
2026-08-03 Model updated to have pump startup surge current even with forced flags
2026-08-03 Push button restart tested, fixed, working
    [pump_chip.sv]
2026-08-04 test 7 : setup mode operation sweep ref with led feedback
2026-08-04 fixed debounce to state vs pulse, and corrected setup mode led behavior.
2026-08-04 Test 8 : 24 hour auto pump test (at 16x speed on fpga = 90min). Hooked up virtual LED to dev boad LEDs
2026-08-04 Actually wire in the 24hr restart so test can run and pass
2026-08-05 Match switch polarities to silkscreen, and update tests correspondingly.
2026-08-06 Shorted GL tests and conditionalliy remove white box probes during GL
    [test.py]
2026-08-06 no deep rtl probes during GL sims
2026-08-06 Pump model startup current immediatly upon pump turn on.
2026-08-07 Enhance README with project description
    Added a brief project description and clarified the purpose of the Liquid Pump Controller.
2026-08-08 Swap run and time leds in forge fpga
2026-08-08 Update DB pcb and sch files to 0.5.1 to reflect swapped run/tile LEDs with correct net names. No change to PCB
    [dev_board.kicad_pcb, dev_board.kicad_sch]
2026-08-10 Bring over emu tested feature changes for forge and TT flow tests
2026-08-12 Artefacts 140a866 from successful 70sec pump-empty field trial (~70 gallons). apparatus shown.
2026-08-25 Forge running against Test_V1 max10. First running forge LPC.
    [dev_board.kicad_sch]
2026-08-26 fixup sim asserts threhsolds
    [test.py]
2026-08-27 Enhance documentation for pump-out chip functionality
    Expanded the explanation of the pump-out chip's functionality, including details about the datasheet, block diagrams, and development board. Improved clarity on testing methods and external hardware 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
